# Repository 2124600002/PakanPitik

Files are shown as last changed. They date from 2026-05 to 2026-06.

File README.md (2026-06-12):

<div align="center">
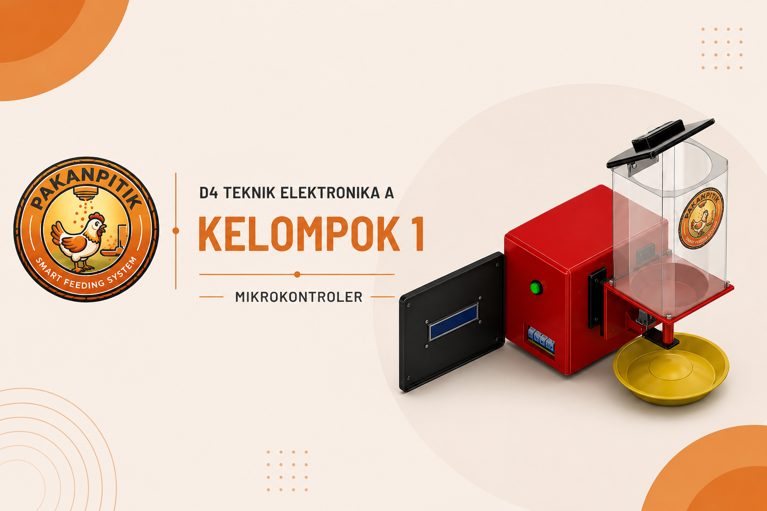
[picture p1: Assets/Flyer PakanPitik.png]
  
  <h1>PakanPitik</h1>
  <p><em>"Inovasi cerdas untuk meringankan beban peternak ayam lokal dan mewujudkan kemandirian pangan"</em></p>
  
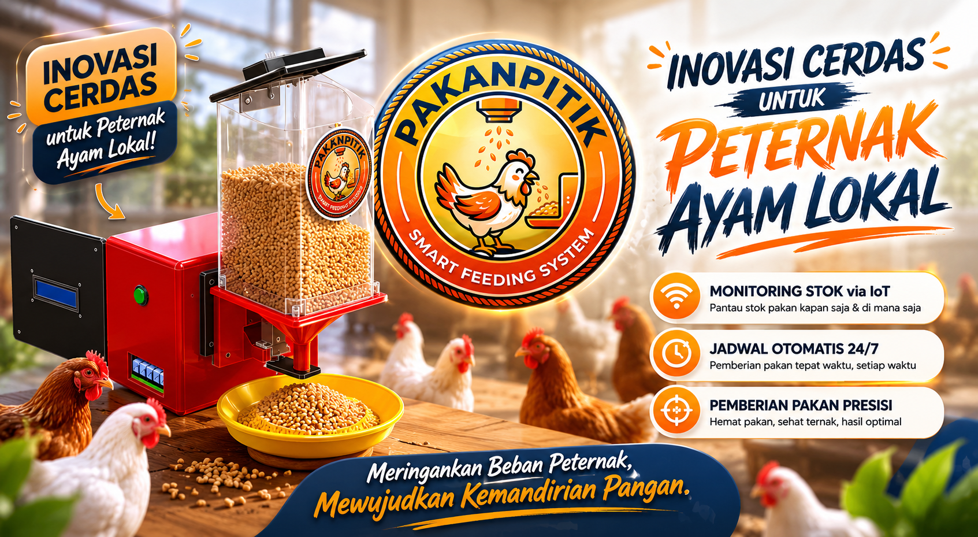
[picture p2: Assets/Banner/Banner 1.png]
  
  <br>

  <a href="https://drive.google.com/file/d/1gD_iWaVMiUkIKPEJ6pST8Kqmy6I9aC7F/view?usp=sharing" target="_blank">
    
  </a>

  <h3>Tautan Cepat (Quick Links)</h3>
  <a href="https://drive.google.com/file/d/1gD_iWaVMiUkIKPEJ6pST8Kqmy6I9aC7F/view?usp=sharing" target="_blank">
    
  </a>&nbsp;
  <a href="https://drive.google.com/file/d/1nLfeXrYmbJYR3gHJrhcpqqbRVYnBJc8w/view?usp=sharing" target="_blank">
    
  </a>&nbsp;
  <a href="https://drive.google.com/file/d/1knvE6YDGjDPh6mzlQrbH5e85_T9ZMVah/view?usp=sharing" target="_blank">
    
  </a>&nbsp;
  <a href="https://drive.google.com/file/d/19Tj84D4AJFjI7RVErF9s6wRXGpRxHWza/view?usp=sharing" target="_blank">
    
  </a>&nbsp;
  <a href="https://pakanpitik.netlify.app/" target="_blank">
    
  </a>&nbsp;
  <a href="https://www.figma.com/board/ega8brmlDySx4cgtJ8I34z/Mind-Map?node-id=0-1&t=bGIroIMrDm2866S6-1" target="_blank">
    
  </a>&nbsp;
  <a href="https://www.figma.com/board/ZbEIWirykj9XnRzqu0P9ER/Untitled?t=ggg7TkWvkMyIfHQo-1" target="_blank">
    
  </a>&nbsp;
  <a href="https://www.figma.com/design/T8wNbSInKxWhA6DcHFIXEK/Untitled?node-id=0-1&t=T81r4mzvqB2A10Lv-1" target="_blank">
    
  </a>&nbsp;
  <a href="https://wokwi.com/projects/465155487486760961" target="_blank">
    
  </a>&nbsp;
  <a href="https://canva.link/mmxi6qf92nia2kq" target="_blank">
    
  </a>
</div>

<hr>

# Deskripsi Proyek
<div align="justify">
Peternak ayam skala lokal seringkali dihadapkan pada tantangan rutinitas yang menguras waktu dan tenaga. Keterlambatan atau ketidakteraturan jadwal pakan dapat menyebabkan tingkat stres yang tinggi dan pertumbuhan unggas yang tidak merata. Di sisi lain, pemberian pakan secara manual seringkali tidak tertakar dengan baik, berujung pada pakan yang tercecer dan terbuang sia-sia (<em>food waste</em>). Hal ini tentu membebani biaya operasional peternak kecil yang sedang berjuang untuk mencapai kemandirian ekonomi.

Hadir sebagai solusi atas permasalahan tersebut, <strong>PakanPitik</strong> adalah sistem pemberi pakan ayam otomatis berbasis <em>Internet of Things</em> (IoT) yang dirancang aplikatif untuk meringankan beban peternak. PakanPitik mengeliminasi keharusan peternak untuk terus-menerus berada di kandang. Melalui integrasi <em>dashboard</em> cerdas, peternak dapat memantau sisa stok pakan secara <em>real-time</em> dari mana saja, dan sistem akan secara otomatis mendistribusikan pakan secara presisi sesuai jadwal. Dengan adanya fitur penyesuaian durasi pakan yang dinamis, takaran pakan dapat diatur agar selalu pas sesuai umur dan populasi ayam, sehingga menekan kerugian finansial akibat pakan yang terbuang.

Secara teknis, sistem ini menggunakan arsitektur <em>Single Source of Truth</em> (SSOT) di mana <strong>ATmega2560</strong> (diprogram dengan <em>Pure Bare-Metal C++</em>) bertindak sebagai <em>Master Brain</em> yang menangani seluruh logika aktuator dan kepastian waktu secara presisi tanpa <em>delay blocking</em>. Sementara itu, <strong>ESP32</strong> ditugaskan khusus sebagai jembatan jaringan (<em>WiFi Bridge</em>) untuk menghubungkan perangkat fisik di kandang dengan Cloud Web Dashboard.

Untuk mendukung sistem otomatisasi dan monitoring, digunakan beberapa komponen utama:
<ul>
  <li><strong>Ultrasonic Sensor HC-SR04</strong> → Mendeteksi jarak dan menghitung sisa ketersediaan (persentase) pakan dalam wadah penampung (hopper).</li>
  <li><strong>RTC DS3231</strong> → Modul <em>Real-Time Clock</em> untuk menjaga keakuratan jam pemicu jadwal pakan meskipun sistem sempat dimatikan atau putus koneksi internet.</li>
  <li><strong>Tombol Pakan Manual</strong> → Mengizinkan peternak untuk mengeksekusi pakan secara fisik langsung dari kandang (Active LOW) saat melakukan inspeksi.</li>
  <li><strong>Motor Servo MG90</strong> → Digerakkan oleh <em>Hardware Timer Fast PWM</em> untuk membuka dan menutup katup saluran pakan secara akurat.</li>
  <li><strong>LCD 16x2 (I2C)</strong> → Menampilkan informasi jam sistem, sisa stok pakan (%), dan status eksekusi secara lokal di kandang.</li>
  <li><strong>ATmega2560</strong> → Mikrokontroler AVR utama pusat kendali (<em>Master</em>).</li>
  <li><strong>ESP32</strong> → Penghubung internet via WiFi untuk sinkronisasi data ke <em>database</em> jarak jauh (<em>Slave/Bridge</em>).</li>
</ul>

Melalui sentuhan otomatisasi tepat guna ini, PakanPitik tidak hanya meningkatkan efisiensi waktu dan tenaga, tetapi juga memberdayakan peternak lokal agar dapat mengelola peternakannya dengan lebih modern, produktif, dan sejahtera.
</div>

# Tujuan Proyek
<div align="justify">
Merancang dan mengimplementasikan sistem pemberian pakan unggas otomatis berbasis IoT untuk memantau ketersediaan pakan secara <em>real-time</em> dan mengontrol aktuator distribusi pakan (berbasis jadwal atau <em>remote on-demand</em>). Proyek ini ditujukan untuk mempermudah pekerjaan peternak, mencegah pakan terbuang percuma melalui fitur durasi dinamis, dan menaikkan efisiensi operasional kandang.
</div>

### Support By :
>- **Dosen Pengampu** : Akhmad Hendriawan ST., MT.
>- **Mata kuliah** : Mikrokontroler
>- **Program Studi** : D4 Teknik Elektronika A
>- **Politeknik Elektronika Negeri Surabaya**

<hr>

# Anggota Kelompok 1

<div align="center">
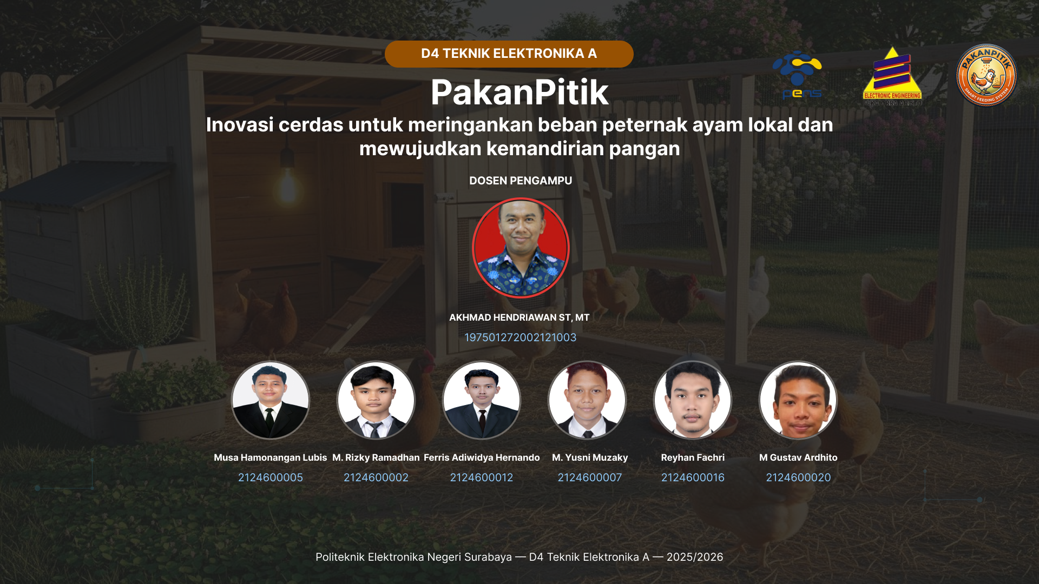
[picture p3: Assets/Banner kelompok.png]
  
</div>
<br>

| NRP | Nama | Jobdesk |
| :---: |:---:  | :---: |
| 2124600002 | M. Rizky Ramadhan  | Project Manager |
| 2124600005 | Musa Hamonangan L. | UI/UX Design |
| 2124600007 | Muh Yusni Muzaky F.| Hardware |
| 2124600012 | Ferris Adiwidya H. | Software & Documentation|
| 2124600016 | Reyhan Fachri A.H. | Software & Documentation|
| 2124600020 | M Gustav Ardhito | Hardware |

# Komponen Hardware

<div align="justify">
<ol>
  <li>Mikrokontroler ATmega2560 (Master Controller)</li>
  <li>Modul ESP32 WiFi (Bridge Controller)</li>
  <li>Modul Real-Time Clock (RTC) DS3231</li>
  <li>Sensor Jarak Ultrasonik HC-SR04</li>
  <li>Motor Servo DC MG90/MG996R</li>
  <li>Modul Display LCD 16x2 + I2C Backpack (PCF8574)</li>
  <li>Push Button (Tactile Switch)</li>
  <li>Modul Step-Down DC-DC LM2596 (12V ke 5V)</li>
  <li>Logic Level Converter Bi-Directional (Jembatan UART 5V ↔ 3.3V)</li>
  <li>Power Supply 12V DC</li>
</ol>
</div>

<hr>

# Visualisasi Sistem

### Desain Hardware 
<div align="center">
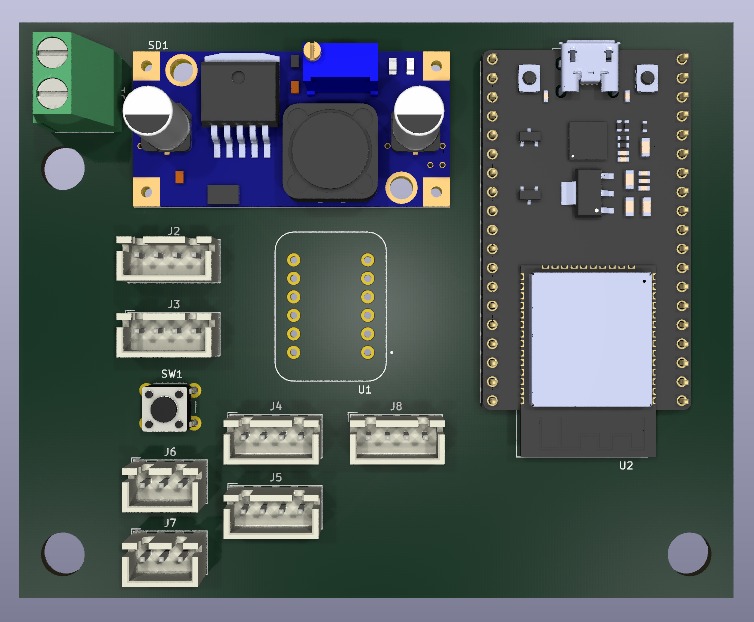
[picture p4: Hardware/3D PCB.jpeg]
  
  <p align="justify">
    Tampilan 3D dari board PCB slave untuk sistem PakanPitik.
  </p>
  
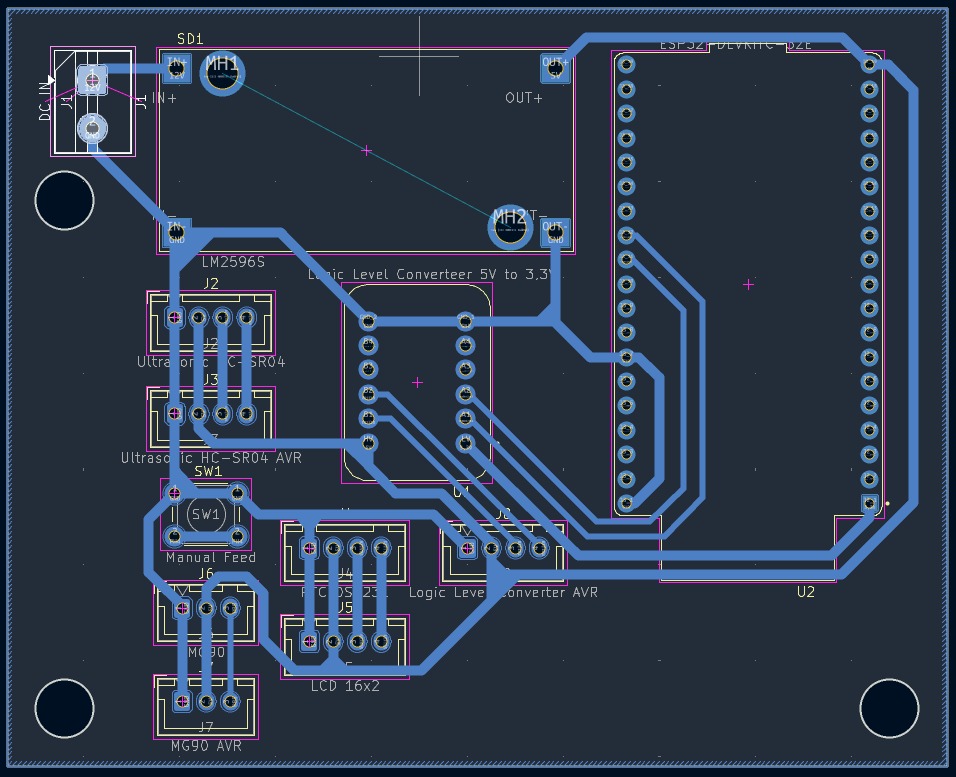
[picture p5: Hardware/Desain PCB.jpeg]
  
  <p align="justify">
    Wiring pada board PCB slave dengan menggunakan bottom layer saja untuk menghemat biaya dan mempermudah dalam proses pencetakan.
  </p>

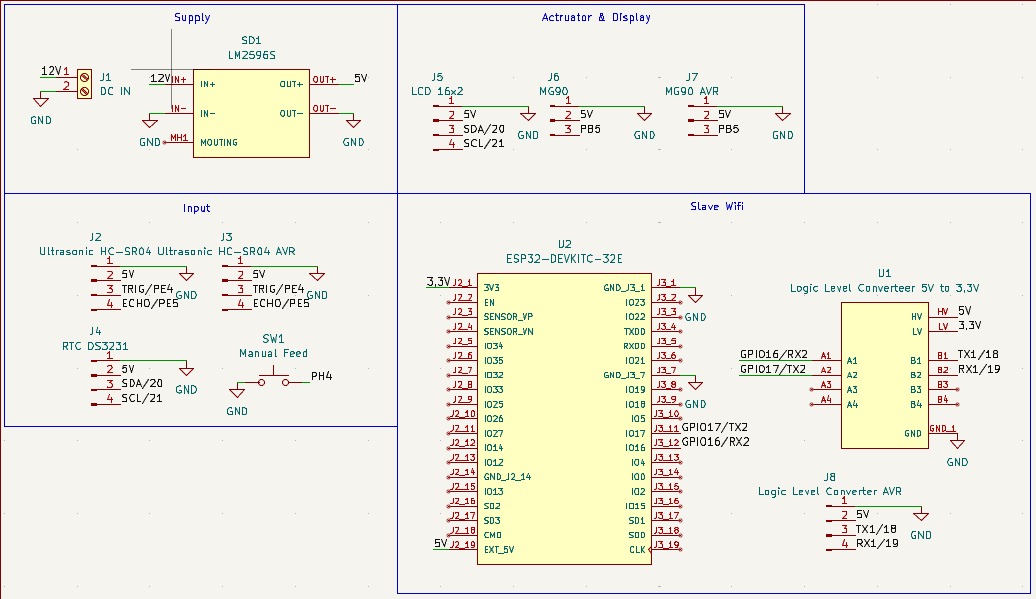
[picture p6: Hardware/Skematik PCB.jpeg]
  
  <p align="justify">
    Desain skematik dari board PCB slave yang digunakan pada PakanPitik, dimana dari board PCB slave ini nantinya akan banyak dihubungkan menggunakan konektor JST melalui kabel menuju board shield ATmega2560.
  </p>
</div>
<br>

### Desain 3D
<div align="center">
<br>
  <a href="https://drive.google.com/file/d/19Tj84D4AJFjI7RVErF9s6wRXGpRxHWza/view?usp=sharing" target="_blank">
    
  </a>
  <br><br>
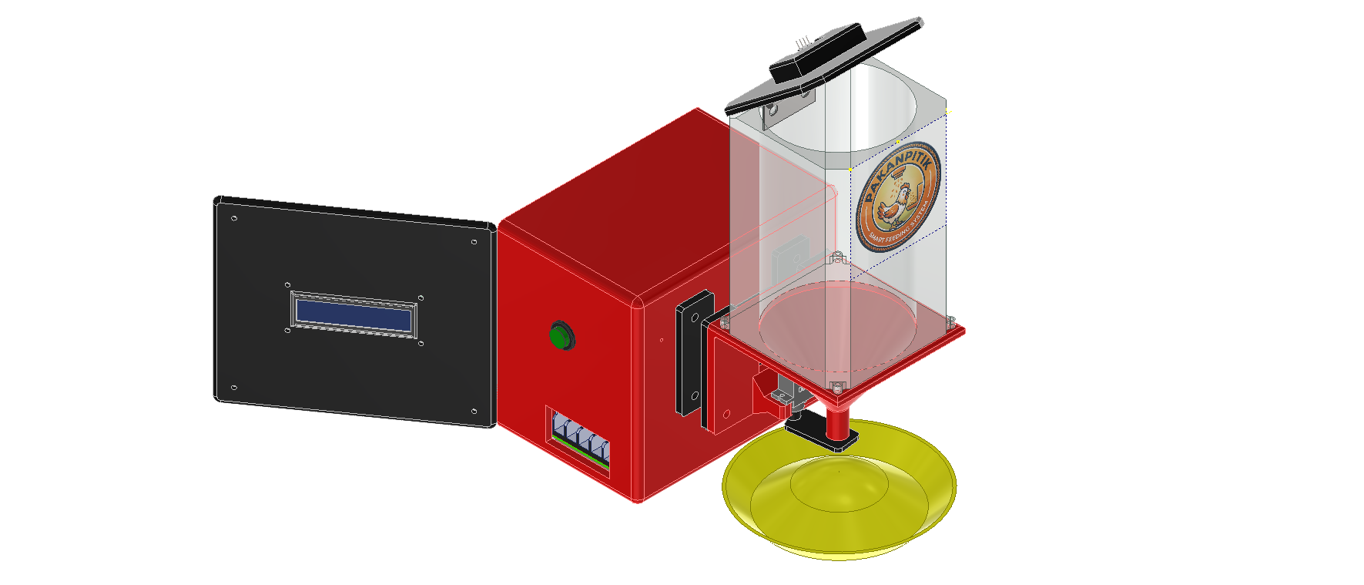
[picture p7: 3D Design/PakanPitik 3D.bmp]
  
  <p align="justify">
    Tampak desain 3D dari PakanPitik yang dirancang menggunakan perangkat lunak Inventor. Pada desain tersebut, dapat dilihat penampung makanan unggas, servo sebagai aktuator untuk membuka dan menutup saluran pakan melalui corong, serta bracket penghubung antara alat pemberi pakan dan box IoT. Bracket ini dapat digunakan untuk menggantungkan alat pada triplek atau papan dengan ketebalan 2cm. Terdapat juga box IoT yang pada bagian depannya dilengkapi LCD 16x2 I2C, tombol pakan manual berwarna hijau, serta port input untuk power supply 12V 5A di bagian bawah. Selain itu, piring atau wadah pakan ditempatkan di bagian bawah penampung sebagai area keluarnya pakan.
  </p>

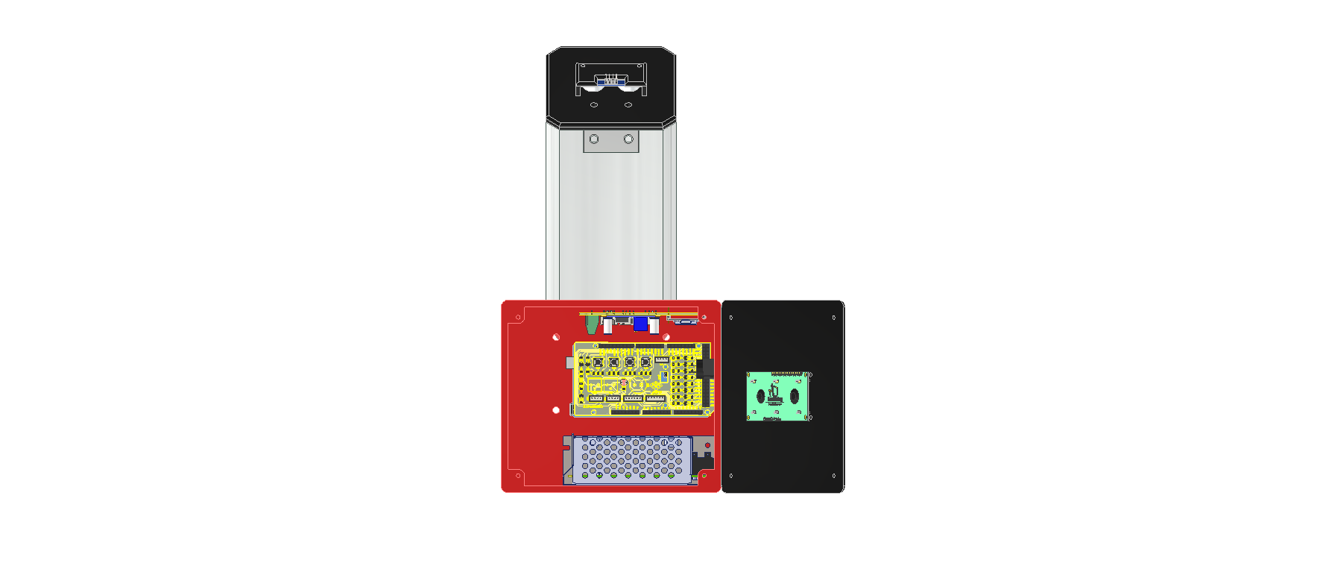
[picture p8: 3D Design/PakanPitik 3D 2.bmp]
  
  <p align="justify">
    Tampak bagian dalam Box IoT yang memuat shield dan board ATmega2560 sebagai master, board slave untuk komunikasi sensor dan aktuator, serta ESP32 sebagai modul WiFi (modul WiFi ini dapat diganti dengan alternatif yang lebih terjangkau, namun ESP32 dipilih karena ketersediaan perangkat). LCD 16x2 terpasang pada penutup box, sedangkan Power Supply 12V 5A berfungsi sebagai sumber daya utama. Penggunaan Power Supply langsung dipilih alih-alih adaptor biasa agar sistem mampu beroperasi secara stabil dan tangguh selama 24 jam nonstop.
  </p>

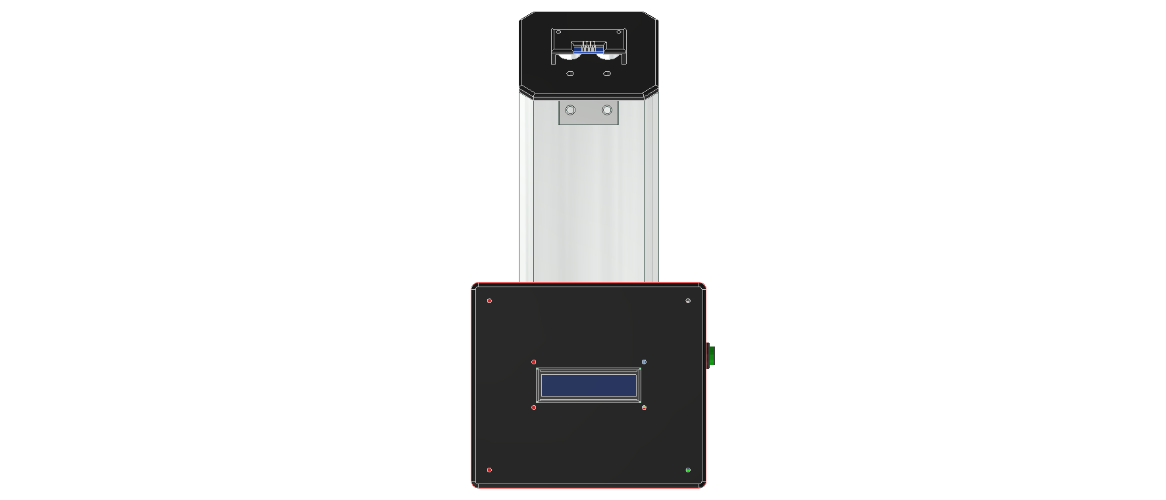
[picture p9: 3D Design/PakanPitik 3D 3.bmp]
  
  <p align="justify">
    Tampak depan dari alat PakanPitik saat box tertutup, dengan LCD 16x2 yang berfungsi sebagai layar informasi sistem.
  </p>

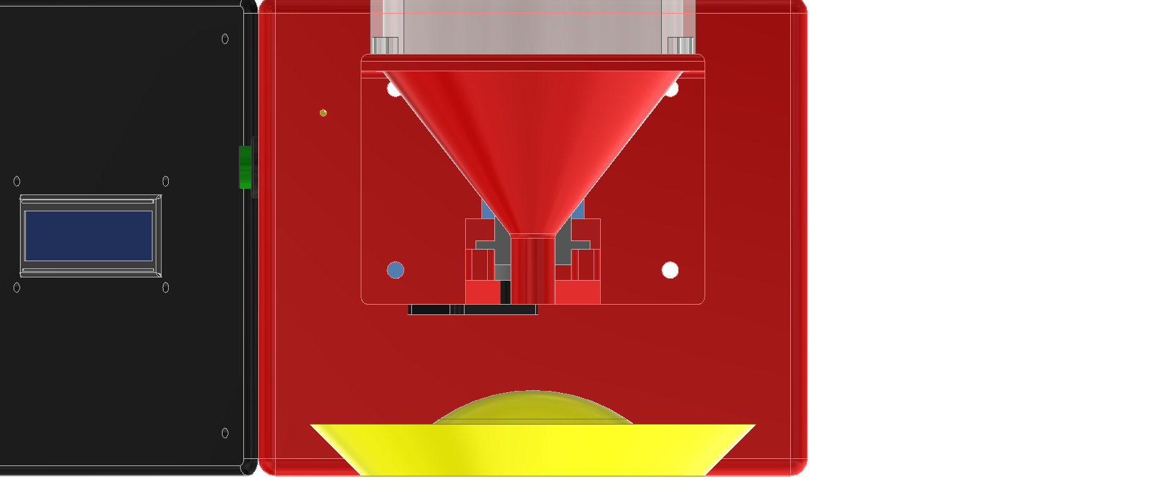
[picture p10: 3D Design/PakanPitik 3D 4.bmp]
  
  <p align="justify">
    Tampak bagian corong di dasar penampung pakan, dilengkapi dengan penutup yang digerakkan oleh servo MG90 untuk memastikan daya tahan yang cukup kuat.
  </p>

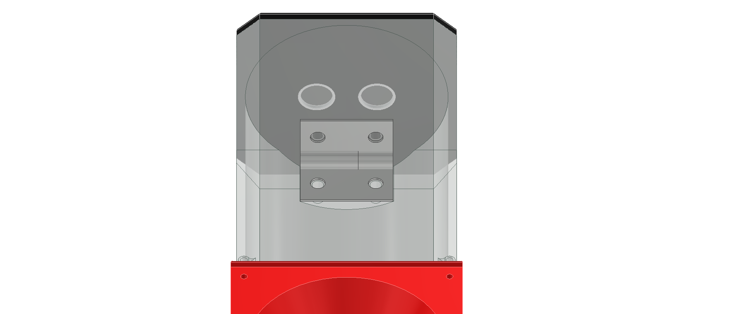
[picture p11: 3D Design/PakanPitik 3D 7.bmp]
  
  <p align="justify">
    Penempatan sensor ultrasonik pada penutup paling atas penampung pakan, menghadap ke bawah. Fungsinya adalah untuk mengukur level atau sisa pakan di dalam wadah secara real-time.
  </p>

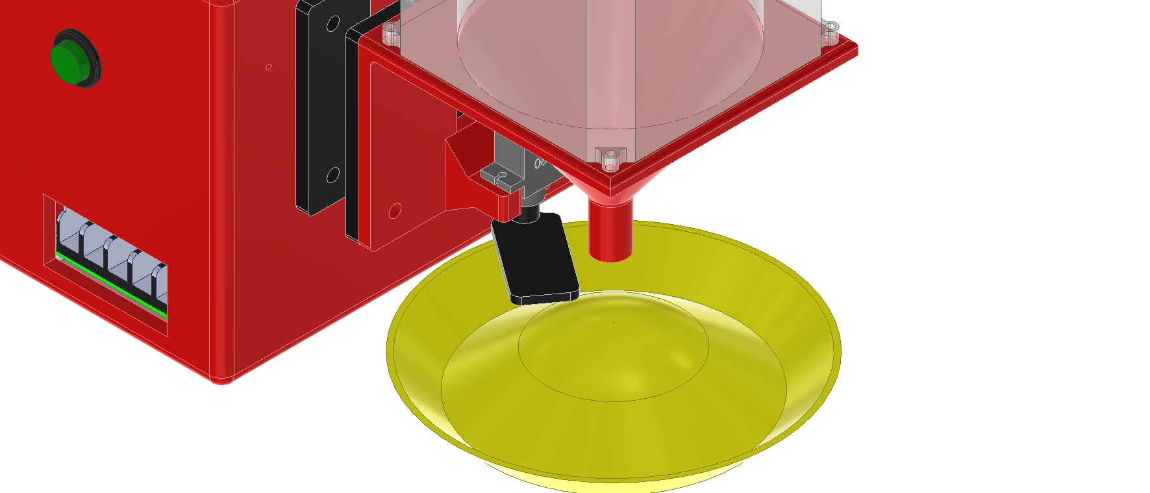
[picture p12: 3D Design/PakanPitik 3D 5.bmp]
  
  <p align="justify">
    Posisi servo saat terbuka. Ketika jadwal pakan otomatis tiba atau tombol pakan manual ditekan, servo akan membuka katup. Durasi bukaan ini dapat diatur langsung melalui antarmuka GUI (Web Dashboard).
  </p>

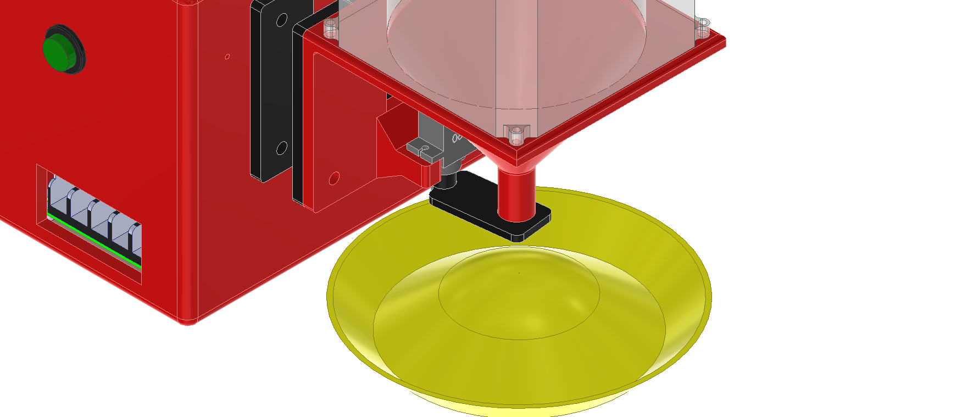
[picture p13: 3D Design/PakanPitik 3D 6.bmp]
  
  <p align="justify">
    Posisi servo saat tertutup. Saat sistem sedang tidak aktif atau belum mencapai waktu pemberian pakan otomatis, servo akan menutup rapat bagian bawah corong penampung untuk mencegah pakan keluar secara tidak sengaja dan menghindari masuknya semut atau hama lain ke dalam wadah.
  </p>
</div>
<br>

### Blok Diagram
<div align="center">
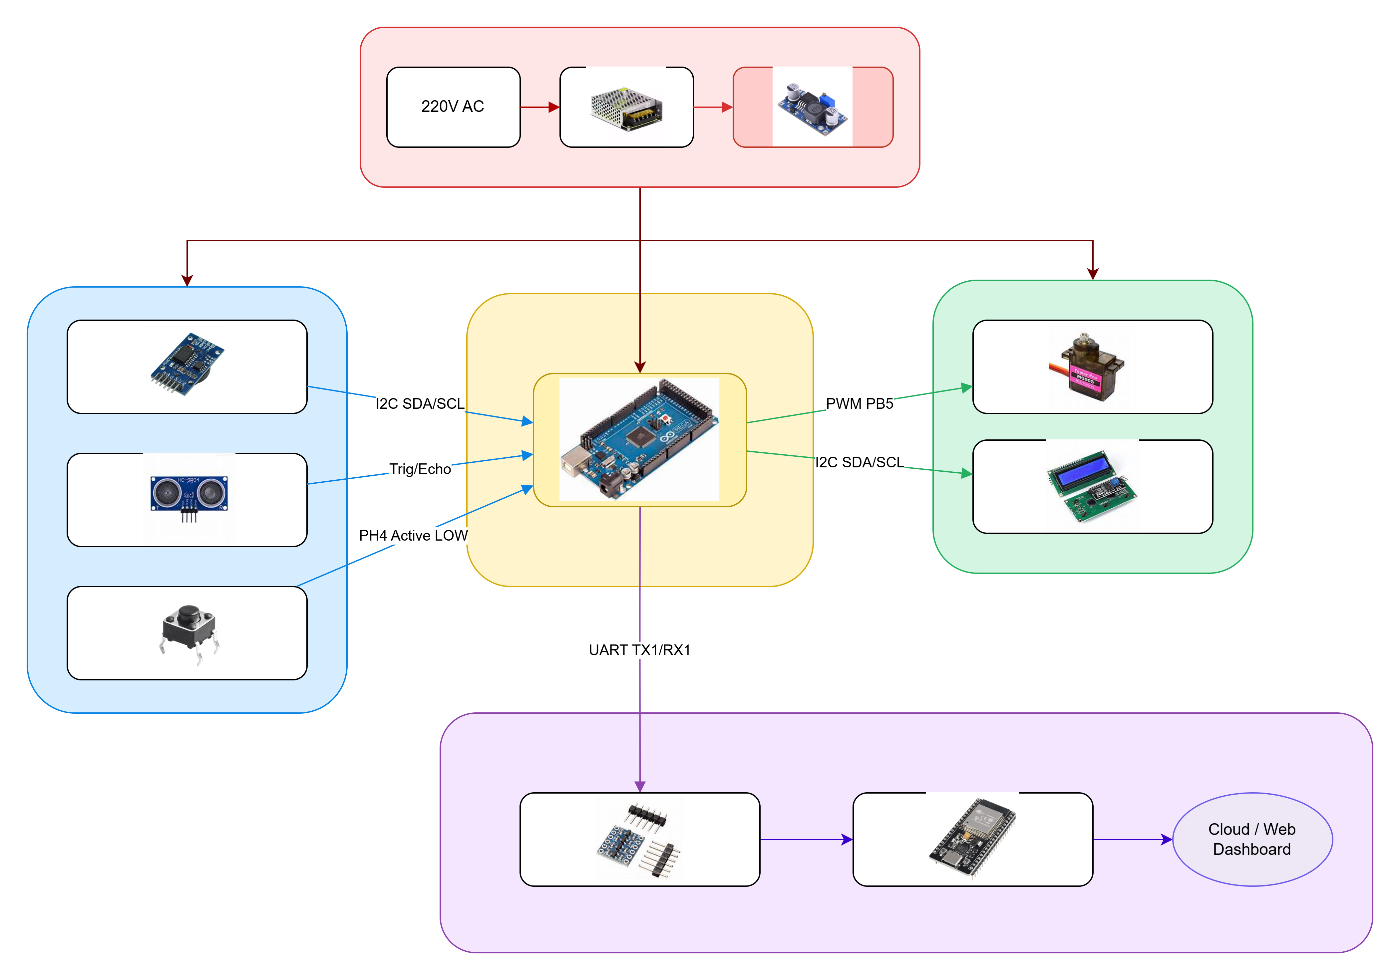
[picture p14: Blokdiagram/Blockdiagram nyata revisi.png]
  
  <p align="justify">
    Blok diagram di atas merepresentasikan alur koneksi dan komunikasi dari perangkat keras PakanPitik yang sebenarnya (sistem nyata terimplementasi), bukan adaptasi sementara berbasis Shield ATmega2560.
  </p>
</div>
<br>

### Flowchart
<div align="center">
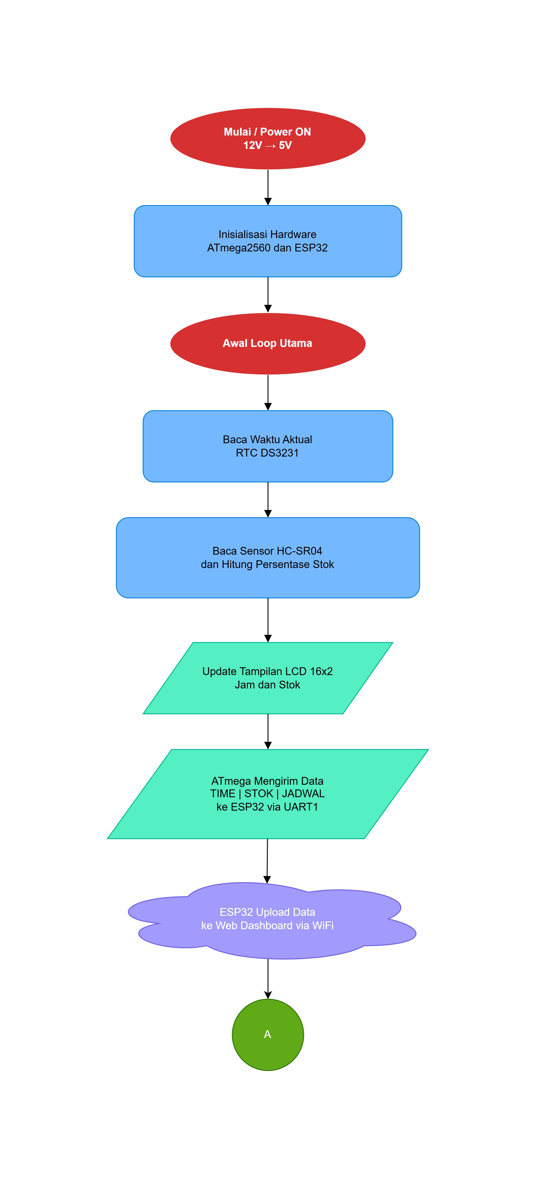
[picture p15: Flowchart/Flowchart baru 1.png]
  
  <p align="justify">
    Flowchart logika yang menggambarkan alur kerja sistem PakanPitik (Bagian Pertama).
  </p>

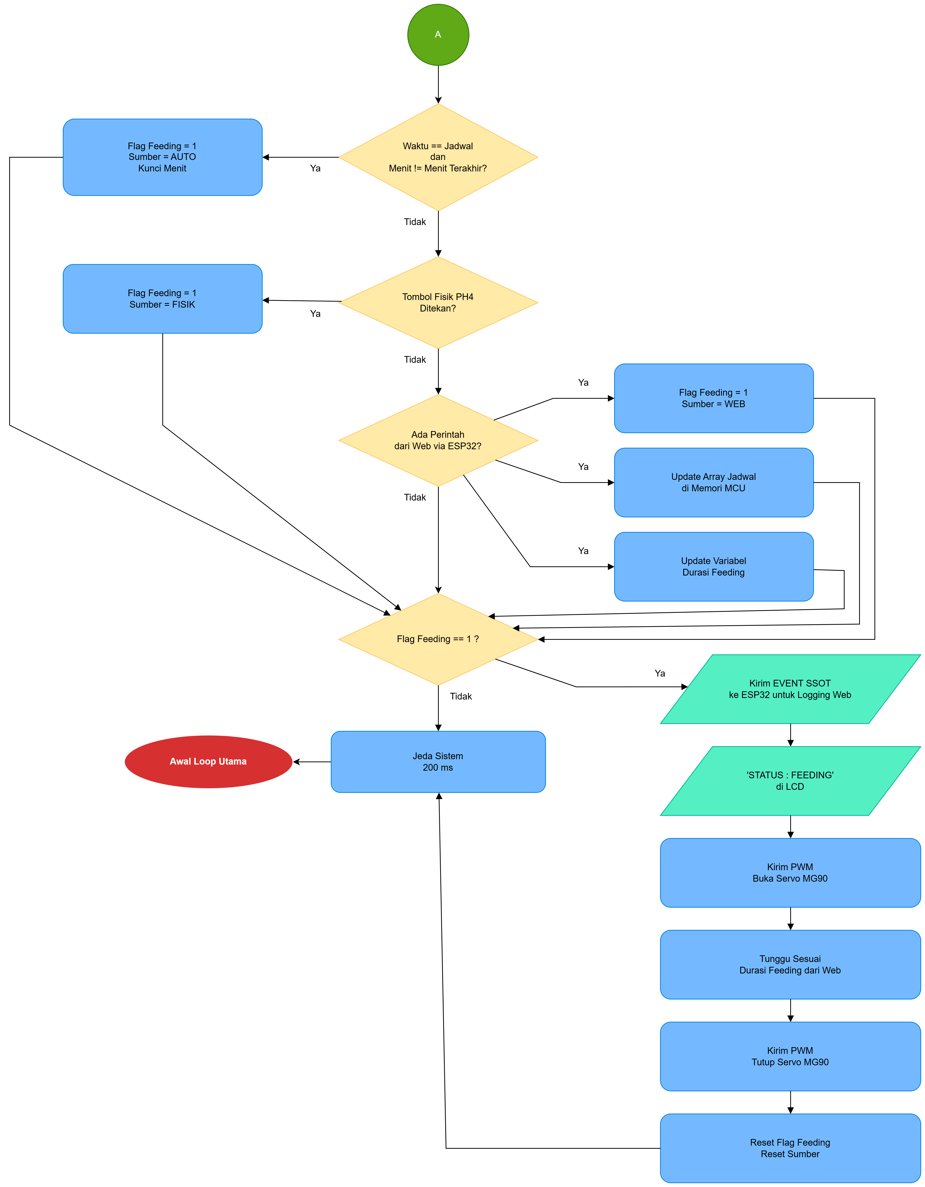
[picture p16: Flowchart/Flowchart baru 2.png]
  
  <p align="justify">
    Flowchart logika yang menggambarkan alur kerja sistem PakanPitik (Bagian Kedua).
  </p>
</div>
<br>

### Mindmap Diagram
<div align="center">
  <br>
  <a href="https://www.figma.com/board/ega8brmlDySx4cgtJ8I34z/Mind-Map?node-id=0-1&t=bGIroIMrDm2866S6-1" target="_blank">
    
  </a>
  <br><br>
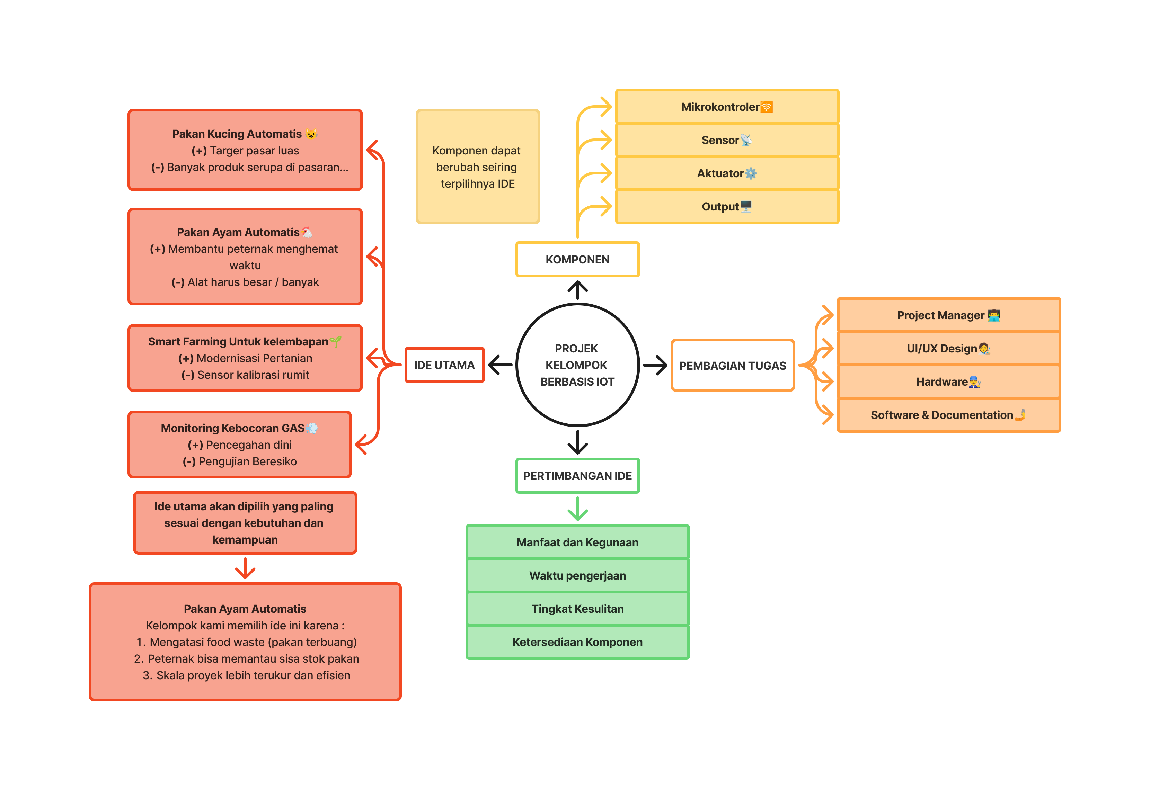
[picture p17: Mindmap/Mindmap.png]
  
  <p align="justify">
    Mindmap ini menggambarkan tahapan brainstorming dan perencanaan strategis awal untuk proyek kelompok berbasis IoT. Diagram ini memetakan beberapa alternatif ide penyelesaian masalah, kriteria utama dalam menyeleksi ide (seperti manfaat, waktu, kesulitan, dan ketersediaan komponen), hingga gambaran umum kebutuhan perangkat keras. Melalui pemetaan ini, kelompok secara spesifik memutuskan untuk mengembangkan Pakan Ayam Otomatis (PakanPitik) karena dinilai paling efektif dalam mengatasi food waste, memungkinkan pemantauan sisa stok pakan, dan memiliki skala proyek yang terukur. Selain itu, diagram ini juga memperlihatkan struktur pembagian tugas masing-masing anggota tim.
  </p>
</div>
<br>

### Fishbone Diagram
<div align="center">
  <br>
  <a href="https://www.figma.com/board/ZbEIWirykj9XnRzqu0P9ER/Untitled?t=ggg7TkWvkMyIfHQo-1" target="_blank">
    
  </a>
  <br><br>
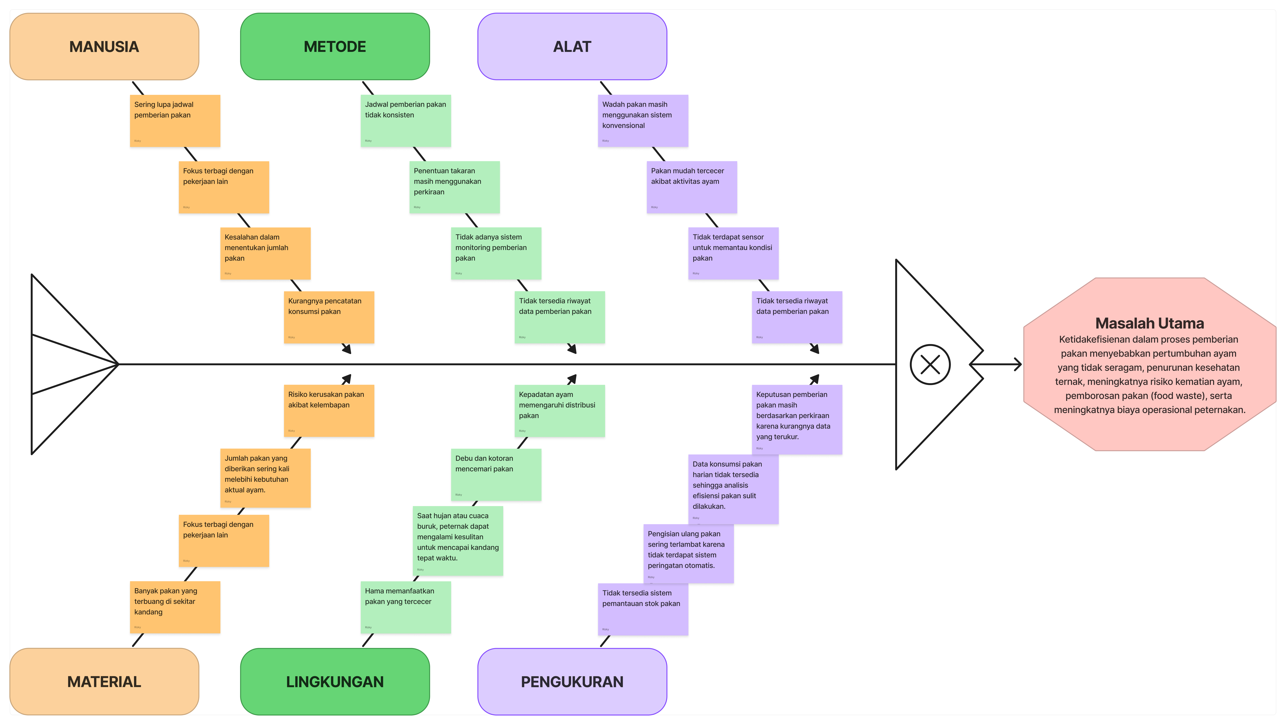
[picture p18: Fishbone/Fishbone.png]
  
  <p align="justify">
   Diagram Fishbone digunakan untuk membedah akar permasalahan dari ketidakefisienan proses pemberian pakan unggas secara manual. Diagram ini mengkategorikan penyebab masalah ke dalam enam aspek utama, yaitu manusia, metode, alat, material, lingkungan, dan pengukuran (seperti sering lupa jadwal, wadah konvensional yang membuat pakan tercecer, hingga tidak adanya riwayat data konsumsi). Secara keseluruhan, akumulasi dari keenam faktor tersebut bermuara pada satu masalah utama yang merugikan peternak, yaitu pemborosan pakan (food waste), ketidakseragaman pertumbuhan ayam, serta melambungnya biaya operasional.
  </p>
</div>
<br>

### UI/UX Web Dashboard
<div align="center">
  <br>
  <a href="https://www.figma.com/design/T8wNbSInKxWhA6DcHFIXEK/Untitled?node-id=0-1&t=T81r4mzvqB2A10Lv-1" target="_blank">
    
  </a>&nbsp;
  <a href="https://pakanpitik.netlify.app/" target="_blank">
    
  </a>
  <br><br>
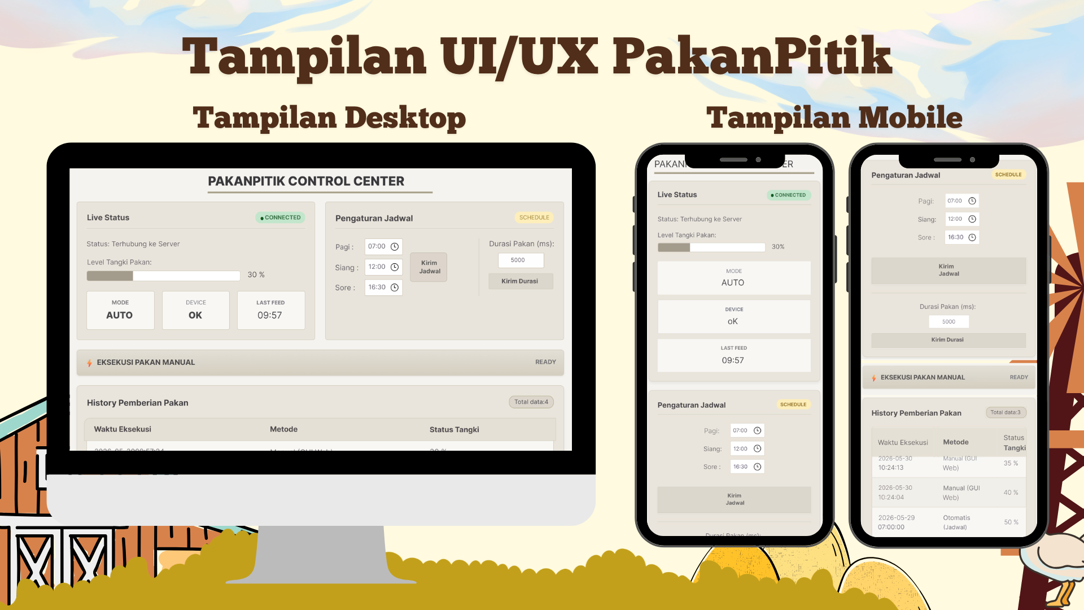
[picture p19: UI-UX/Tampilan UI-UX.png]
  
  <p align="justify">
    Tampilan UI/UX Web Dashboard yang dirancang menggunakan Figma untuk memantau alat PakanPitik via WiFi di berbagai perangkat. Panel "Live Status" menampilkan persentase sisa pakan di penampung (berdasarkan pembacaan sensor Ultrasonik HC-SR04) dan waktu pemberian pakan terakhir. Di sebelah kanan, terdapat form untuk mengatur jadwal pakan otomatis (Pagi, Siang, Sore) beserta input durasi bukaan servo (dalam milidetik). Di bagian tengah, tersedia tombol interaktif untuk mengeksekusi pemberian pakan secara manual. Bagian paling bawah menampilkan tabel log history yang mencatat detail setiap aktivitas operasional alat secara real-time.
  </p>
</div>
<br>

### Simulasi Program Wokwi
<div align="center">
  <br>
  <a href="https://wokwi.com/projects/465155487486760961" target="_blank">
    
  </a>
  <br><br>
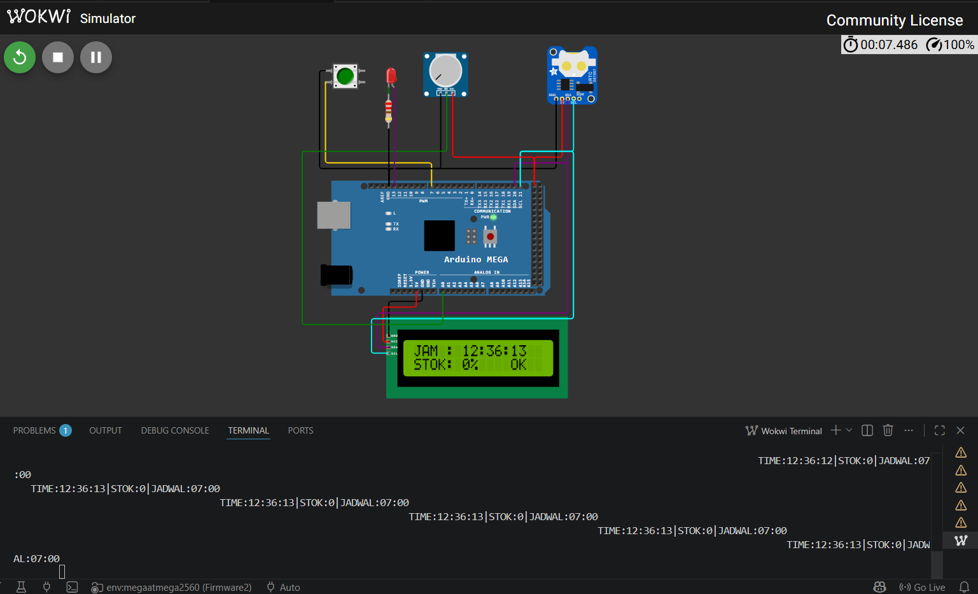
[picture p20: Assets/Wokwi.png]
  
  <p align="justify">
    Tangkapan layar di atas menunjukkan pengujian simulasi logika sistem PakanPitik yang sementara ini disesuaikan dengan komponen input/output yang tersedia pada Shield PCB ATmega2560.
  </p>
</div>

<hr>

# Cara Kerja Sistem
<div align="justify">
<ol>
  <li><strong>Inisialisasi & Pembacaan Data:</strong> Saat dihidupkan, ATmega2560 menarik data waktu <em>real-time</em> (Jam, Menit, Detik) dari RTC DS3231 via I2C, serta mengukur pantulan frekuensi dari HC-SR04 untuk dikalkulasi menjadi persentase stok pakan (0-100%).</li>
  <li><strong>Sinkronisasi Tampilan & Cloud:</strong> Data waktu dan stok ditampilkan ke layar LCD 16x2. Secara bersamaan, ATmega2560 merangkai string data dan mengirimkannya melalui komunikasi Serial (UART1) ke ESP32. ESP32 kemudian menembakkan data tersebut ke Web Dashboard via koneksi WiFi.</li>
  <li><strong>Logika Pemicu (Triggers):</strong> Sistem terus bersiaga memeriksa 3 kondisi pemicu:
    <ul>
      <li><em>Otomatis:</em> Apakah waktu saat ini sama persis dengan jadwal memori? (Dilengkapi <em>debouncing</em> agar tidak terjadi <em>log</em> ganda di detik yang sama).</li>
      <li><em>Fisik:</em> Apakah tombol manual pada kandang ditekan?</li>
      <li><em>Remote:</em> Apakah ada perintah eksekusi pakan masuk dari Web Dashboard melalui ESP32?</li>
    </ul>
  </li>
  <li><strong>Eksekusi Aktuator Dinamis:</strong> Jika salah satu pemicu aktif, ATmega2560 akan memancarkan sinyal <em>Fast PWM</em> (Hardware Timer) untuk membuka katup motor Servo MG90. Lama katup terbuka bergantung pada variabel <strong>Durasi Pakan Dinamis</strong> yang bisa diatur peternak langsung dari Web Dashboard (untuk mencegah pakan terbuang).</li>
  <li><strong>Perekaman Log (History):</strong> Sebelum pakan turun, ATmega2560 secara mutlak mengirimkan paket data <em>Event</em> (<code>EVENT:AUTO</code>, <code>EVENT:PHYSICAL</code>, atau <code>EVENT:GUI</code>) ke Web Dashboard agar waktu dan alasan pakan keluar tercatat rapi di tabel <em>History</em>.</li>
</ol>
</div>

# Panduan Penggunaan
<div align="justify">
<ol>
  <li><strong>Persiapan Daya:</strong> Hubungkan alat ke sumber listrik PLN pada Power Supply 12V nya. Sistem manajemen daya internal (LM2596) akan menstabilkan tegangan operasi komponen ke 5V.</li>
  <li><strong>Koneksi Jaringan:</strong> Pastikan alat menyala dalam jangkauan sinyal WiFi kandang agar ESP32 dapat secara otomatis merutekan sistem ATmega2560 ke <em>database</em> Cloud.</li>
  <li><strong>Akses Dashboard:</strong> Buka <em>browser</em> di <em>smartphone</em> atau PC, lalu akses halaman Web Dashboard PakanPitik milik Anda.</li>
  <li><strong>Pemantauan:</strong> Pada layar Web (atau LCD lokal), Anda dapat melihat jam operasional alat saat ini dan persentase (%) ketersediaan pakan di dalam tangki hopper.</li>
  <li><strong>Pengaturan Jadwal & Durasi:</strong> Pada panel kendali Web, atur 3 jadwal makan utama (Pagi, Siang, Sore) berformat HH:MM. Masukkan juga <strong>Durasi Pakan</strong> dalam milidetik (contoh: isi 3000 untuk buka katup selama 3 detik) untuk menyesuaikan takaran makanan unggas. Tekan "Kirim" atau "Set".</li>
  <li><strong>Eksekusi Darurat:</strong> Jika ingin memberi pakan instan di luar jadwal, tekan tombol fisik pada alat, atau klik tombol <strong>"Beri Makan Manual"</strong> langsung dari Web Dashboard Anda. Log eksekusi akan langsung tercatat pada tabel riwayat <em>website</em>.</li>
</ol>
</div>

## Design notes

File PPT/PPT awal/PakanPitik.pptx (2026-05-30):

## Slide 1


UI UX Design

Project Manager

Software & Documentation

Hardware

Software & Documentation

Hardware

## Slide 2

Mind Mapping FigJam

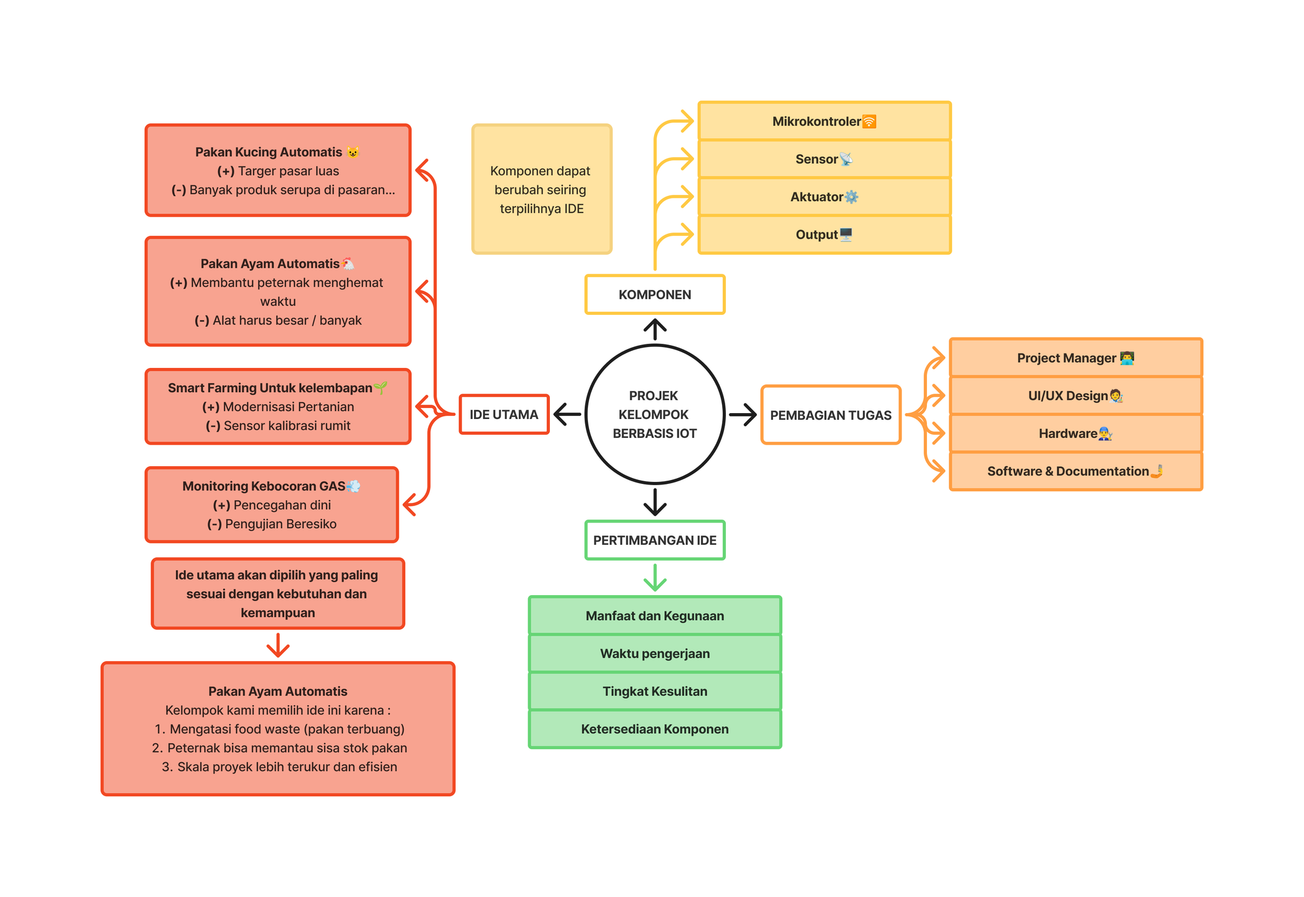
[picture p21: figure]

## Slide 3

Diskripsi Masalah Nyata

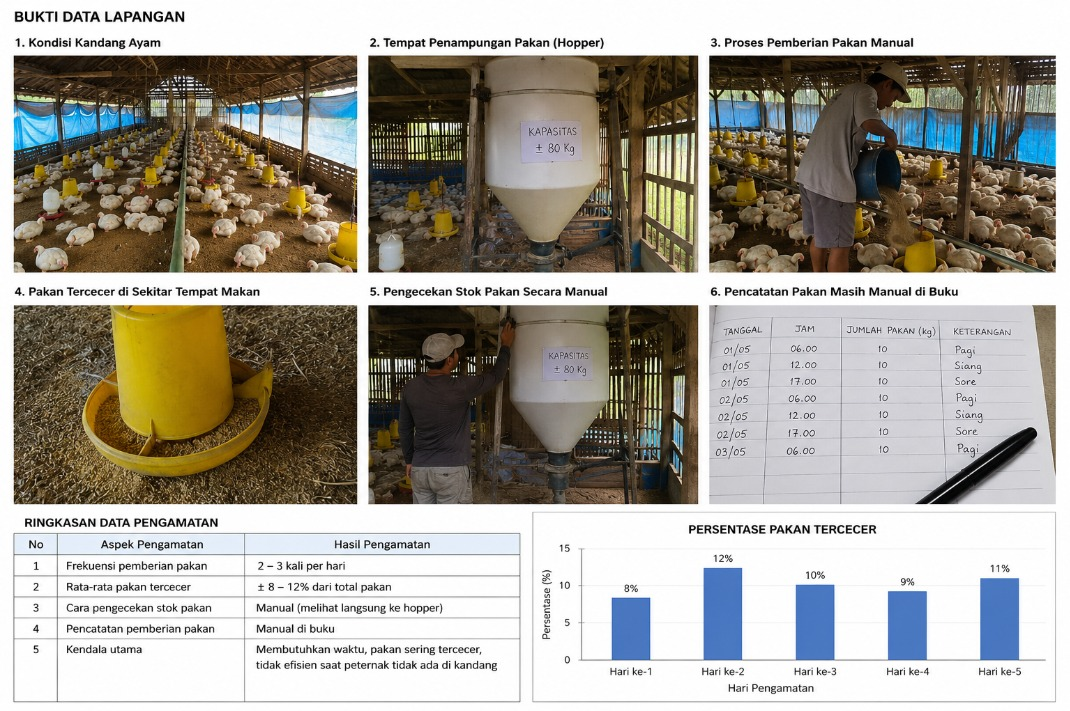
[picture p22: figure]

Project PakanPitik ini kami kembangkan untuk tujuan memenuhi kebutuhan peternak untuk sistem pemberian pakan otomatis yang efisien, dan mampu memantau stok secara real-time, mengurangi pemborosan pakan, dan mempermudah pengelolaan dikandang.

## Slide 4

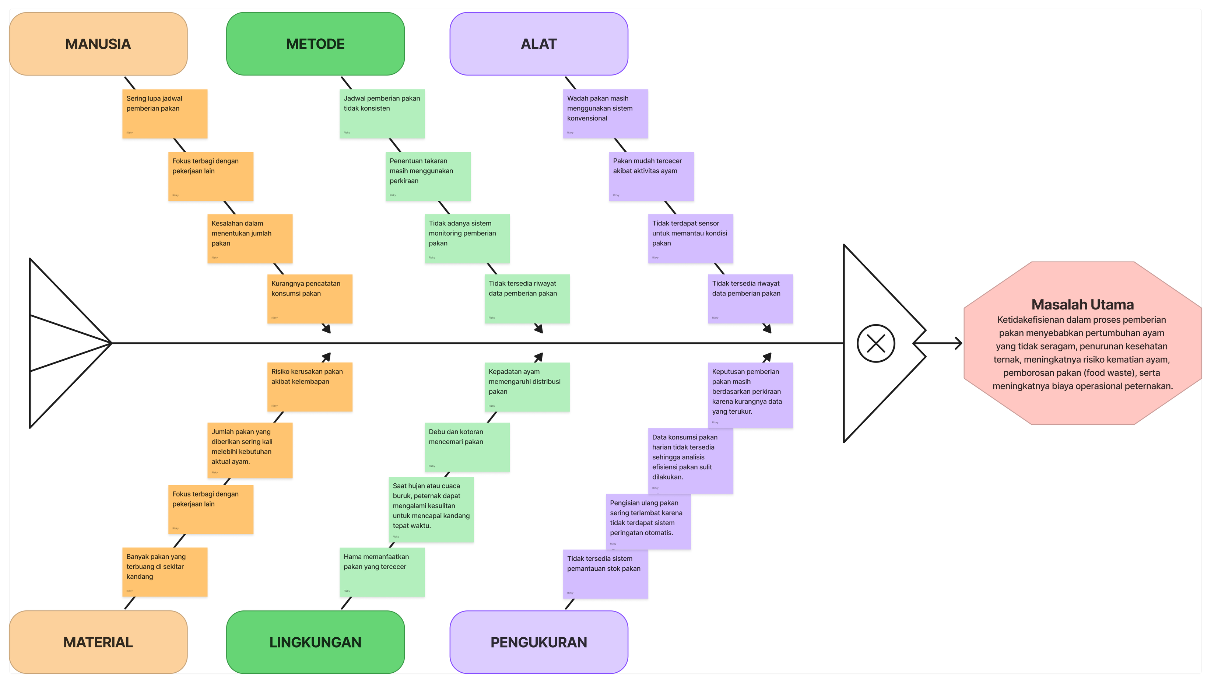
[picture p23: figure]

FishBone Diagram

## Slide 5

SDGs Impact - PakanPitik

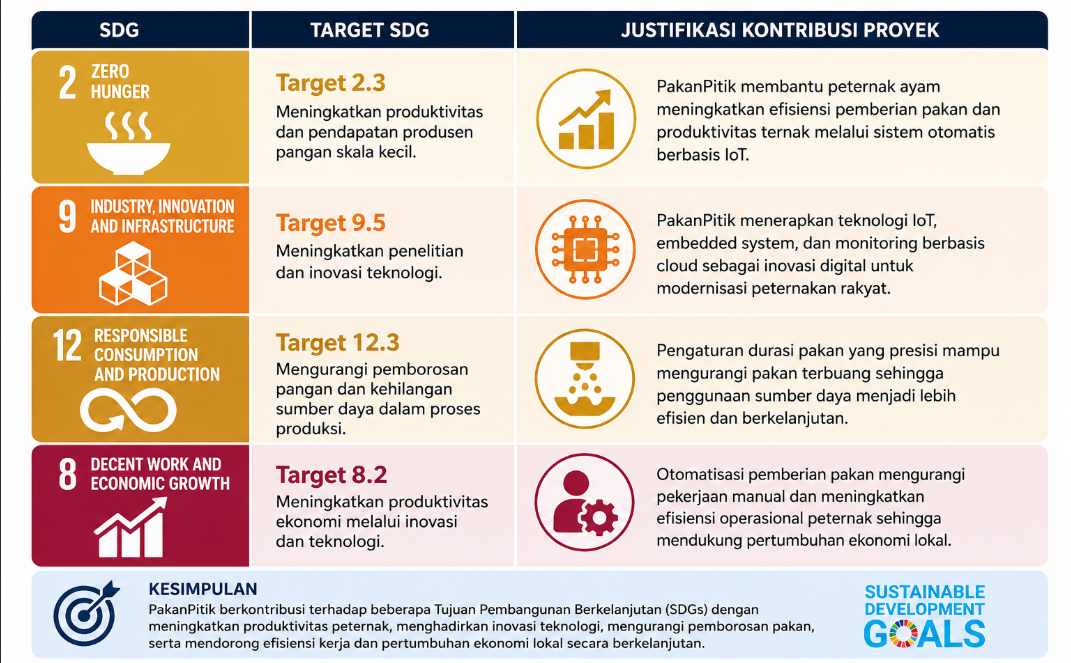
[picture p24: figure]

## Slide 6

Diagram Blok Sistem

Berdasarkan blokdiagram disamping kami menggunakan ATmega2560 yang memiliki fungsi untuk pusat kendali yang akan menerima data dari RTC DS3231, sensor ultrasonic HC-SR04, dan untuk tombol manual. kemudian dari data itu sistem dapat mengontrol servo MG90 untuk menyalurkan pakan secara otomatis. yang dapat kita lihat melalui info yang ada di LED 16 X 2
untuk memantau data stok pakan dan pemberian pakan kita bisa memantau liwat Web dashboard berbasis IoT.

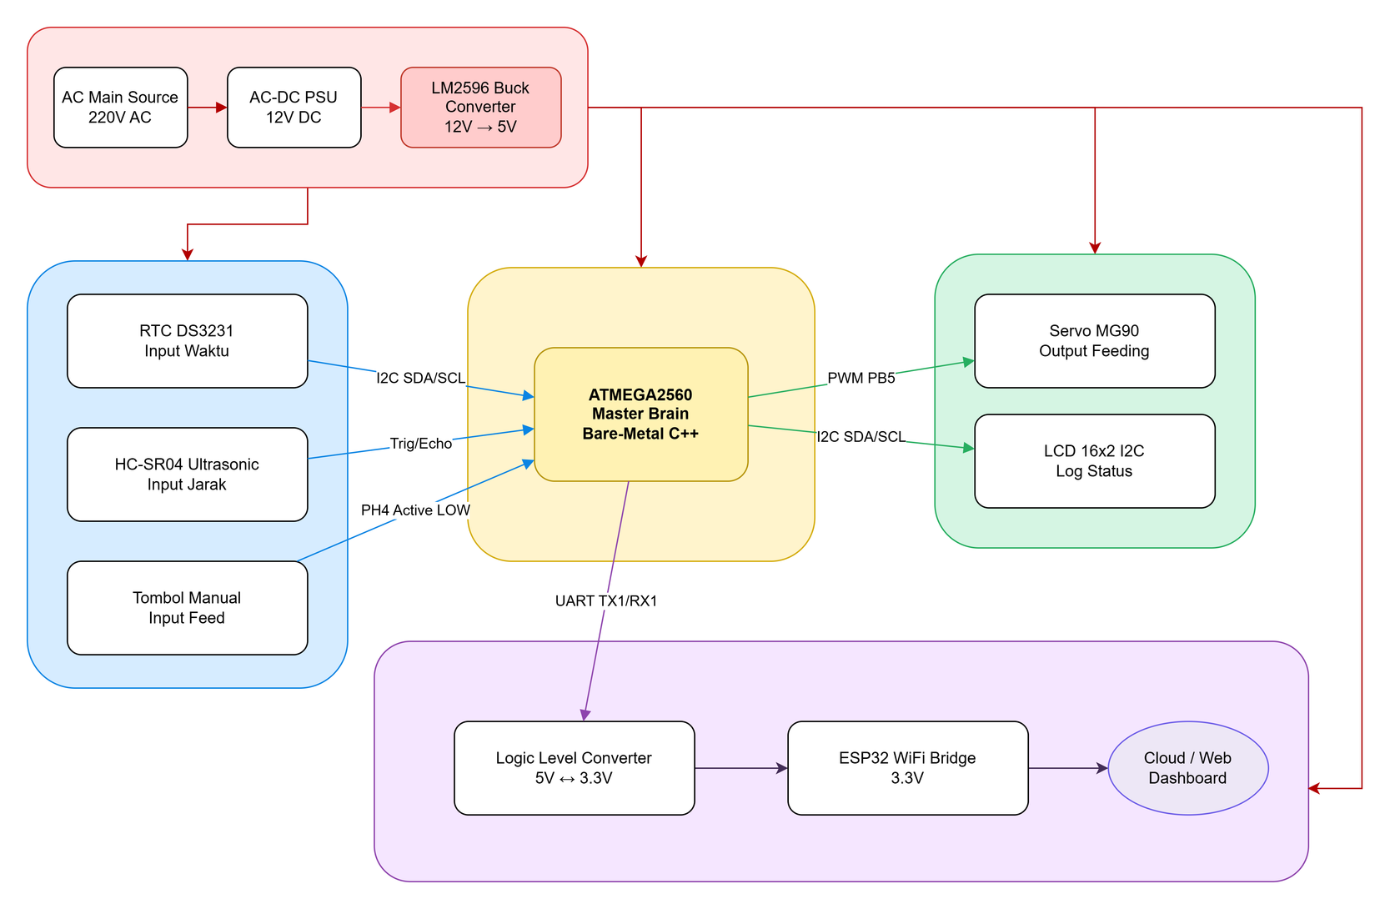
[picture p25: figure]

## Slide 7

UI/UX Desain

User → Dashboard → Atur Jadwal/Durasi → Kirim ke ESP32 → ATmega2560 Memproses → Servo Mengeluarkan Pakan → Data Tersimpan di Cloud → Riwayat & Status Ditampilkan Kembali ke User.

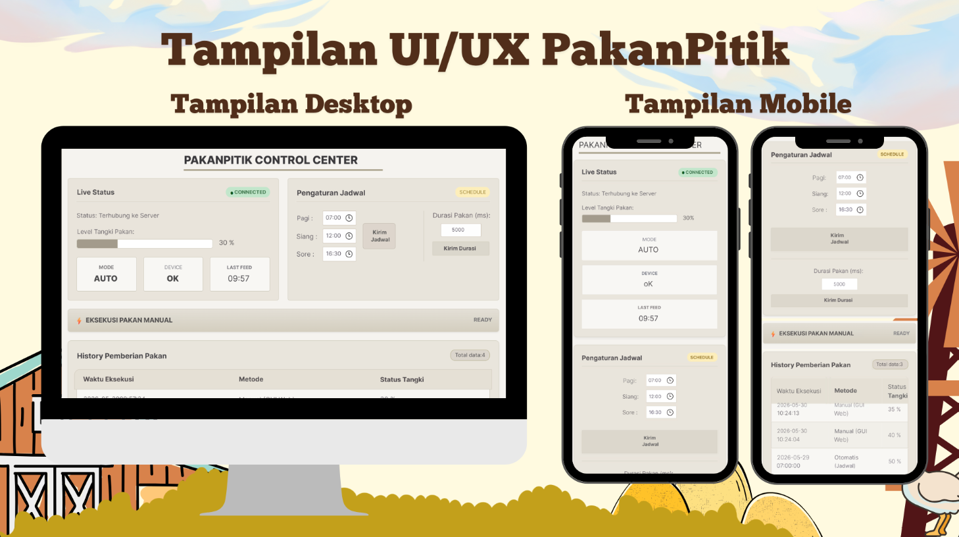
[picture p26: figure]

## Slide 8

Pin Mapping

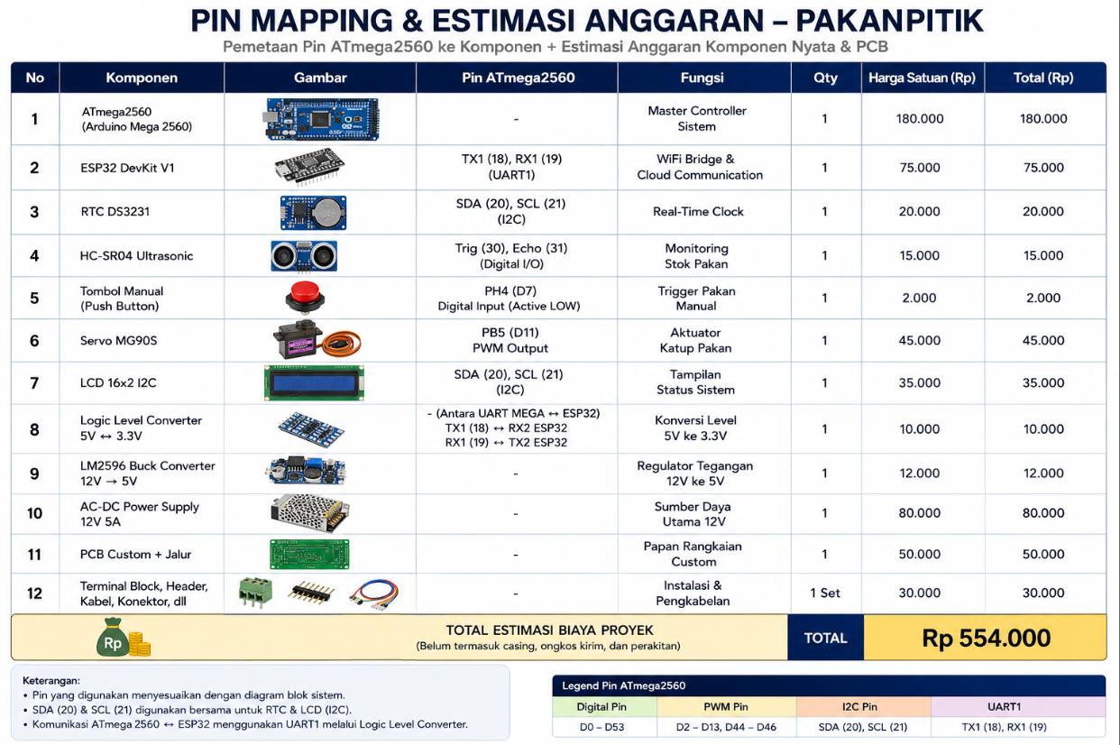
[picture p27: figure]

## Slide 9

Dokumentasi pengerjaan

Contribution Graph GitHub tim.

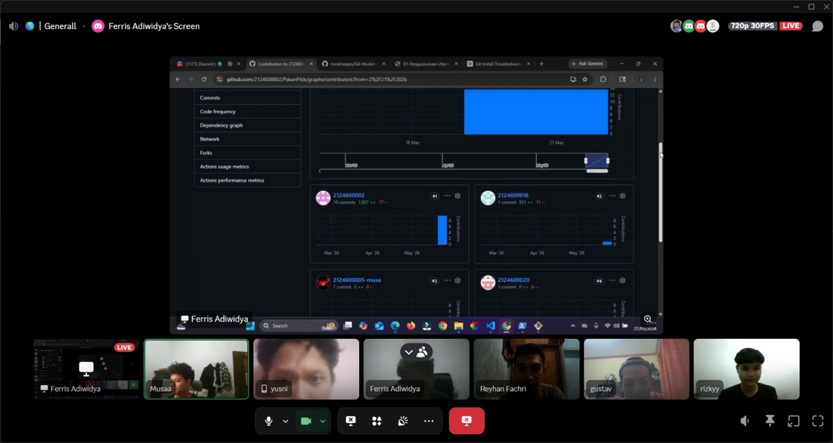
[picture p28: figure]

Diskusi Project

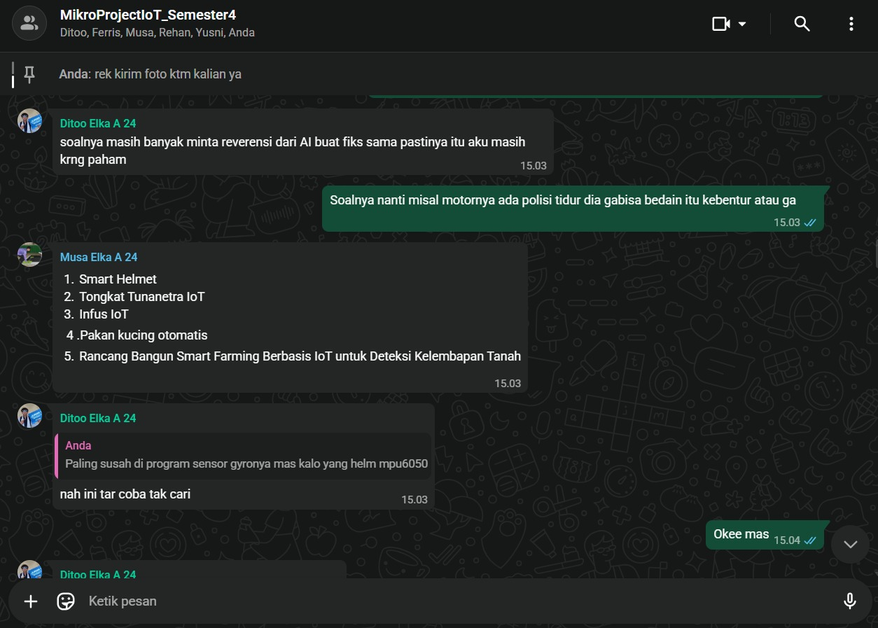
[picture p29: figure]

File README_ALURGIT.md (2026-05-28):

# README_ALURGIT.md

# 📌 Alur Kerja GitHub Project PakanPitik

Dokumen ini digunakan sebagai panduan kerja seluruh anggota tim dalam menggunakan Git & GitHub pada project **PakanPitik** agar workflow tetap rapi, aman, dan terstruktur.

---

# 👨‍💻 Struktur Tim

| Role | Tugas |
| --- | --- |
| Ketua | Review Pull Request, merge ke main, mengatur repository |
| Anggota | Mengerjakan fitur pada branch masing-masing |

---

# 🔒 Aturan Penting

## ❌ DILARANG

* Push langsung ke branch `main`
* Mengubah branch anggota lain
* Menghapus file project tanpa izin
* Force push ke `main`
* Commit file `.pio` atau `.vscode`

---

## ✅ WAJIB

* Kerja di branch masing-masing
* Pull update terbaru sebelum coding
* Commit dengan pesan yang jelas
* Membuat Pull Request setelah selesai bekerja

---

# 🌳 Struktur Branch

| Branch | Fungsi |
| --- | --- |
| `main` | Branch utama project |
| `dito` | Branch kerja Dito |
| `ferris` | Branch kerja Ferris  |
| `musa` | Branch kerja Musa |
| `reyhan` | Branch kerja Reyhan  |
| `yusni`  | Branch kerja Yusni |

---

# 🚀 LANGKAH AWAL SETELAH DIINVITE

---

## 1. Clone Repository

Buka terminal VS Code lalu jalankan:

```bash
git clone git@github.com:2124600002/PakanPitik.git
```

---

## 2. Masuk ke Folder Project

```bash
cd PakanPitik
```

---

## 3. Checkout ke Branch Masing-Masing

Contoh:

```bash
git checkout ferris
```

Ganti `ferris` sesuai nama branch masing-masing anggota.

---

# 🔄 ALUR KERJA HARIAN

Lakukan langkah berikut setiap sebelum dan sesudah bekerja.

---

# 📥 SEBELUM MULAI CODING

## 1. Pastikan berada di branch sendiri

```bash
git branch
```

Jika belum:

```bash
git checkout namabranch
```

---

## 2. Ambil Update Terbaru dari Main

```bash
git pull origin main
```

Tujuan:

* mendapatkan update terbaru dari ketua
* menghindari conflict
* sinkronisasi project

---

# 💻 SETELAH SELESAI CODING

## 1. Tambahkan perubahan

```bash
git add .
```

---

## 2. Commit perubahan

```bash
git commit -m "menambahkan fitur monitoring sensor"
```

Gunakan pesan commit yang jelas dan profesional.

Contoh commit yang baik:

✅

```text
menambahkan pembacaan sensor suhu
memperbaiki bug tombol manual
menambahkan dashboard monitoring
```

❌

```text
fix
baru
update
hehe
```

---

## 3. Push ke Branch Masing-Masing

```bash
git push
```

---

# 🔀 MEMBUAT PULL REQUEST

Setelah push berhasil:

1. Buka repository GitHub
2. Klik tab `Pull Requests`
3. Klik `New Pull Request`
4. Pilih:

   * Base: `main`
   * Compare: `branch masing-masing`
5. Klik `Create Pull Request`

Tambahkan deskripsi perubahan yang dilakukan.

---

# 👑 ALUR REVIEW KETUA

Ketua akan:

1. Review perubahan pada Pull Request
2. Mengecek file yang diubah
3. Memberikan revisi jika diperlukan
4. Approve Pull Request
5. Merge ke branch `main`

---

# 🔄 SETELAH PULL REQUEST DI-MERGE

Semua anggota wajib update branch masing-masing:

```bash
git pull origin main
```

Agar branch tetap sinkron dengan project terbaru.

---

# 🛠 COMMAND PENTING

| Command | Fungsi |
| --- | --- |
| `git status` | Melihat perubahan file |
| `git branch` | Melihat branch aktif |
| `git checkout nama` | Pindah branch |
| `git add .` | Menambahkan semua perubahan |
| `git commit -m "pesan"` | Menyimpan perubahan |
| `git push` | Upload perubahan ke GitHub |
| `git pull origin main`  | Mengambil update terbaru dari main |
| `git log --oneline` | Melihat riwayat commit |

---

# ⚠️ JIKA TERJADI ERROR

## Repository belum update

```bash
git pull origin main
```

---

## Conflict saat merge

Segera hubungi ketua project sebelum melanjutkan.

---

## Salah branch

Pindah branch:

```bash
git checkout namabranch
```

---

# 📌 Catatan Tambahan

* Branch `main` adalah branch paling penting.
* Semua perubahan wajib melalui Pull Request.
* Jangan commit file yang tidak diperlukan.
* Biasakan commit secara rutin.
* Pull update terbaru sebelum coding.

---

# ✅ Workflow Singkat

```text
Pull update terbaru
↓
Coding di branch sendiri
↓
git add .
↓
git commit
↓
git push
↓
Buat Pull Request
↓
Ketua review
↓
Merge ke main
↓
Semua anggota pull update terbaru
```

---

# 🚀 PakanPitik Team Workflow

Developed with structured Git collaboration workflow.

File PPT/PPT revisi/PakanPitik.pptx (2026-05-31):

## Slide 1


UI UX Design

Project Manager

Software & Documentation

Hardware

Software & Documentation

Hardware

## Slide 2


Mind Map Figjam

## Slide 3

Masalah Nyata

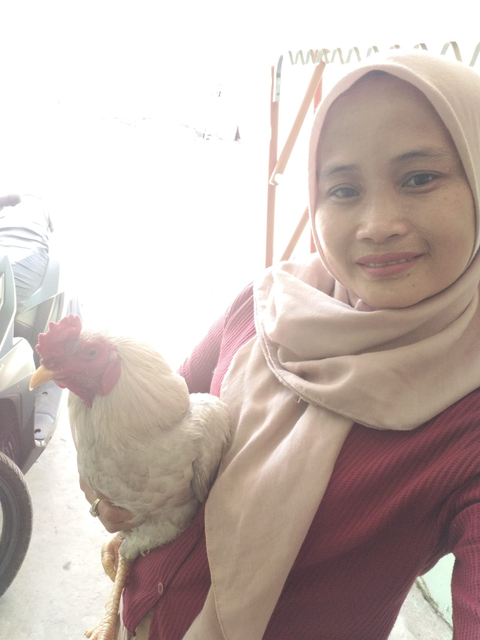
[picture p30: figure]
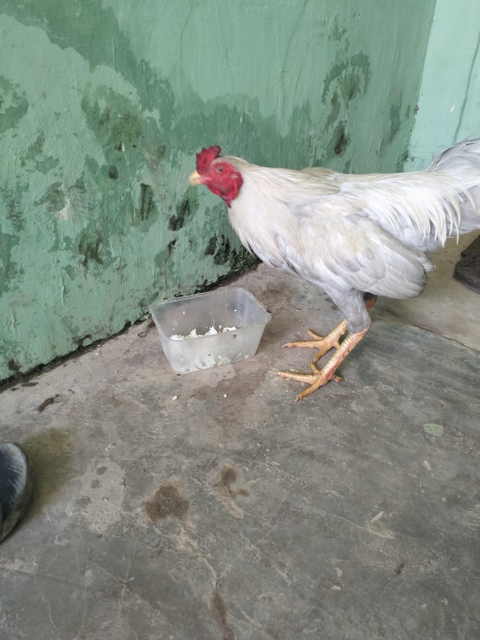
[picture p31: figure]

Rutinitas kerja yang padat membuat pemberian pakan ayam tidak terjadwal dengan konsisten. Keterlambatan atau kelupaan dalam memberi pakan menyebabkan pertumbuhan ayam tidak optimal dan memicu stres pada unggas. Selain itu, pemberian pakan manual yang seringkali "seadanya" berisiko tinggi menyebabkan pakan tercecer atau terbuang sia-sia (food waste), yang menambah beban biaya operasional.

"Terkadang saya harus berangkat kerja pagi sekali dan baru pulang sore hari. Seringkali saya baru ingat memberi pakan siang saat sudah di tempat kerja. Kalaupun ingat, saya terpaksa memberi pakan dalam jumlah banyak sekaligus agar ayam tidak kelaparan, tapi malah banyak yang tumpah dan terinjak-injak karena wadahnya tidak memadai." — Ibu Rizky (Calon Pengguna)

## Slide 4


Fishbone Diagram Figjam

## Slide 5

Sustainable Development Goals Impact


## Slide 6

Block Diagram dan Tabel Mapping

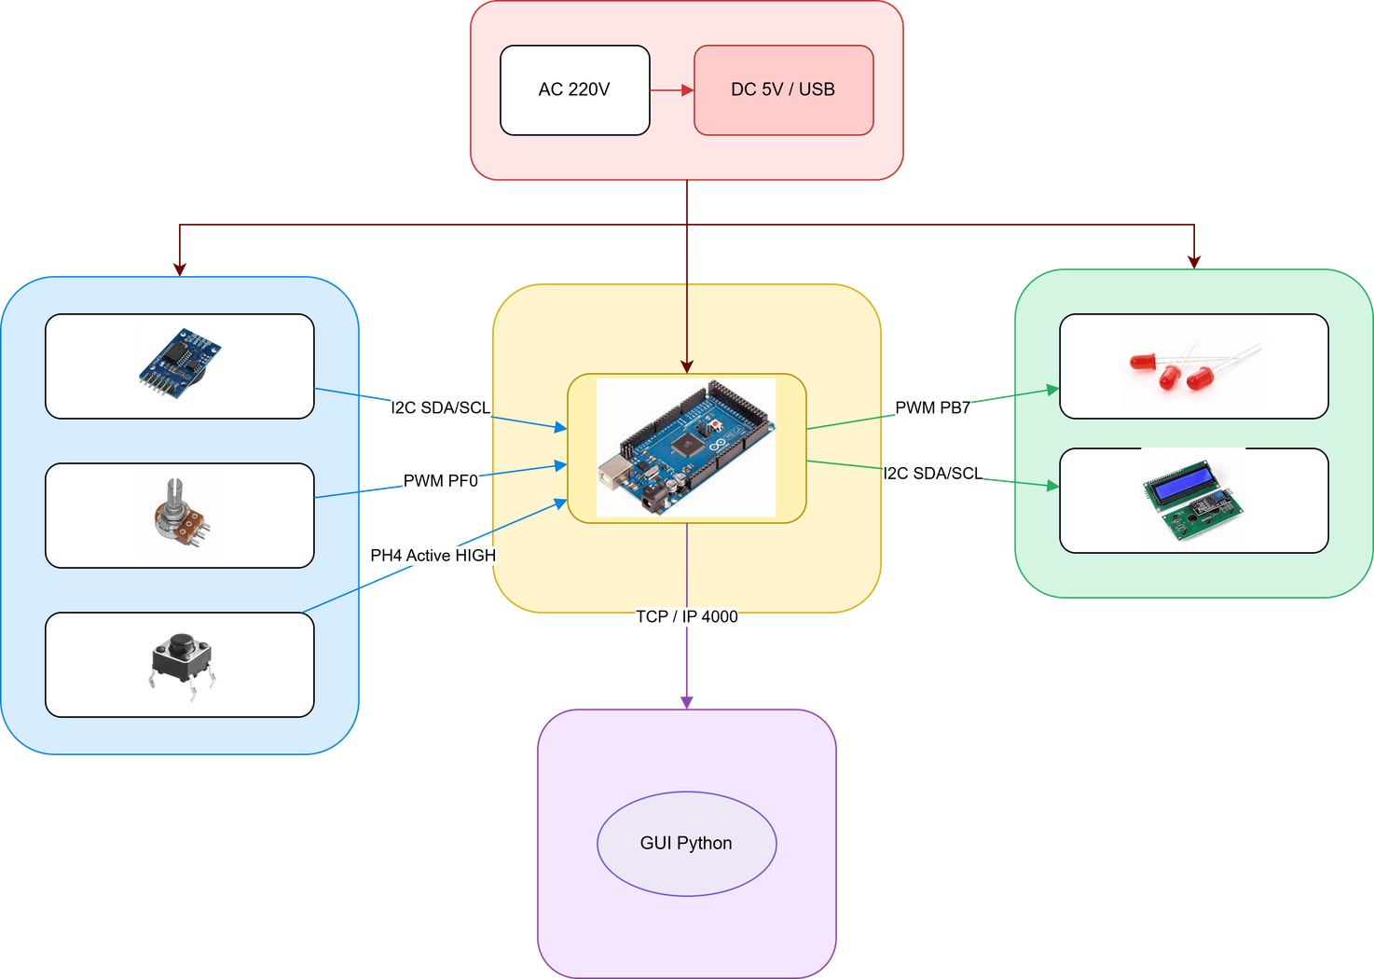
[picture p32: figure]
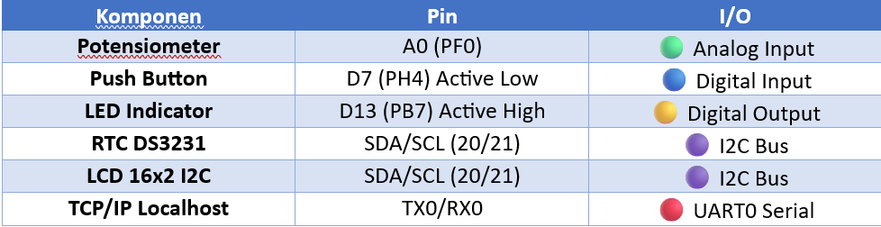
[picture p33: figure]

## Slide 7

UI/UX dan Desain 3D

UI/UX

Desain 3D

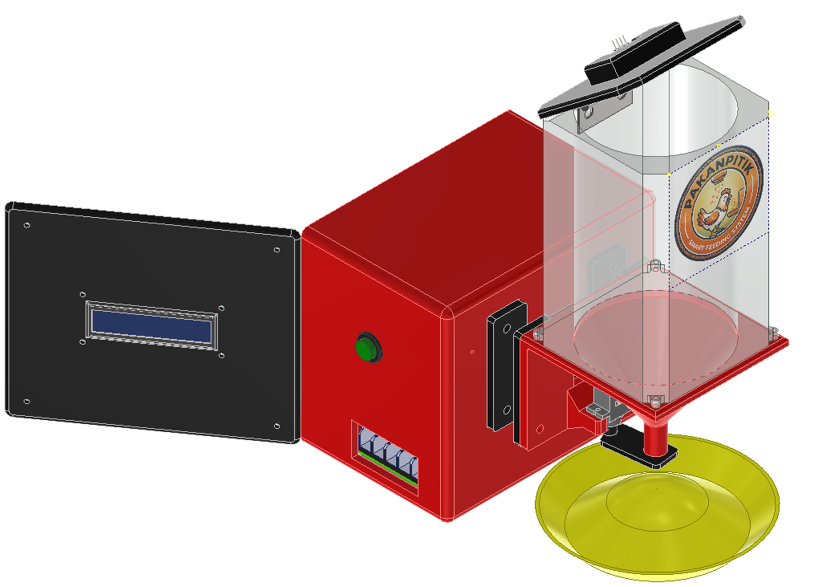
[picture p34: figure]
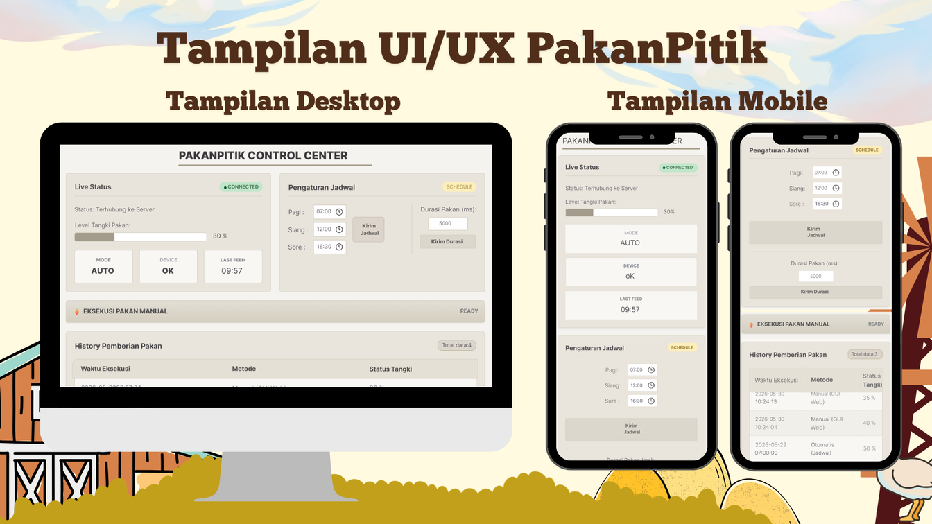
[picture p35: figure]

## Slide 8

Pin Mapping dan RAB

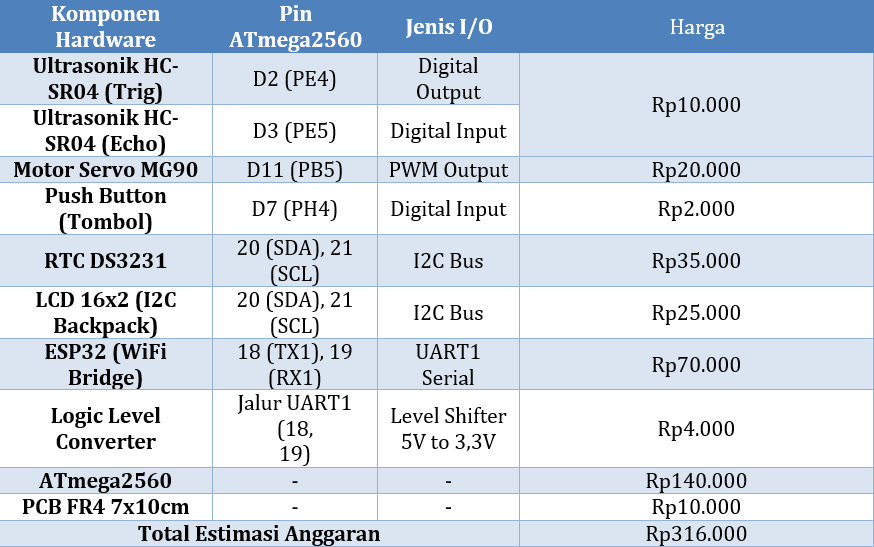
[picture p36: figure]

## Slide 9

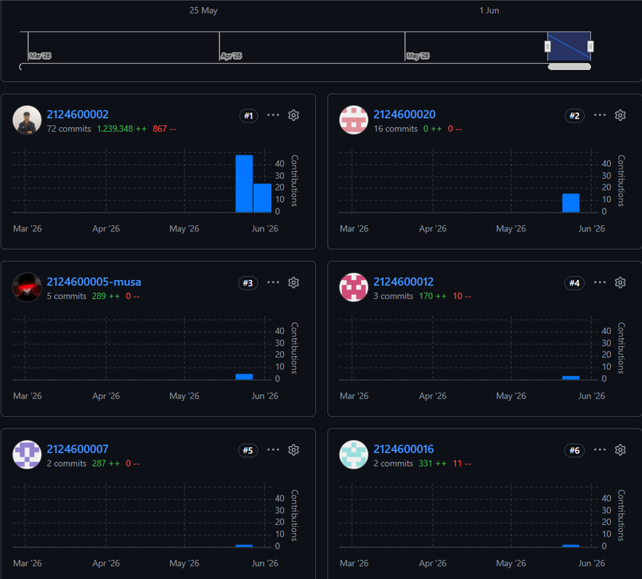
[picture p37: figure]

Dokumentasi Pengerjaan

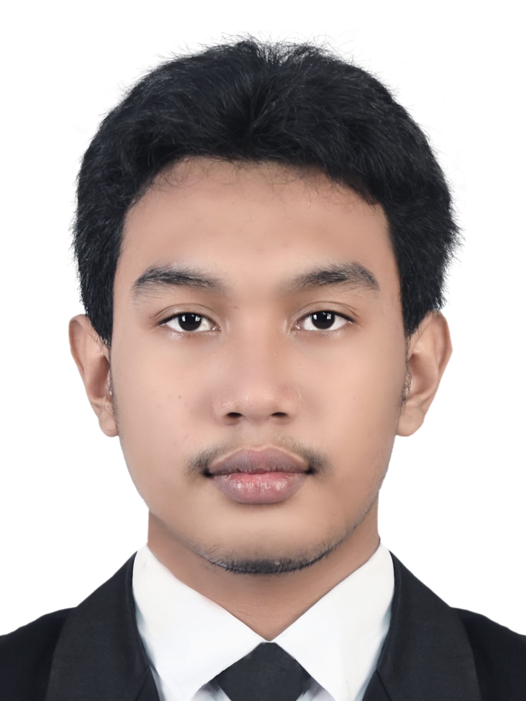
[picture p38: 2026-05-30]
Assets/Foto anggota kelompok/Reyhan Fachri A.H._2124600016.jpeg

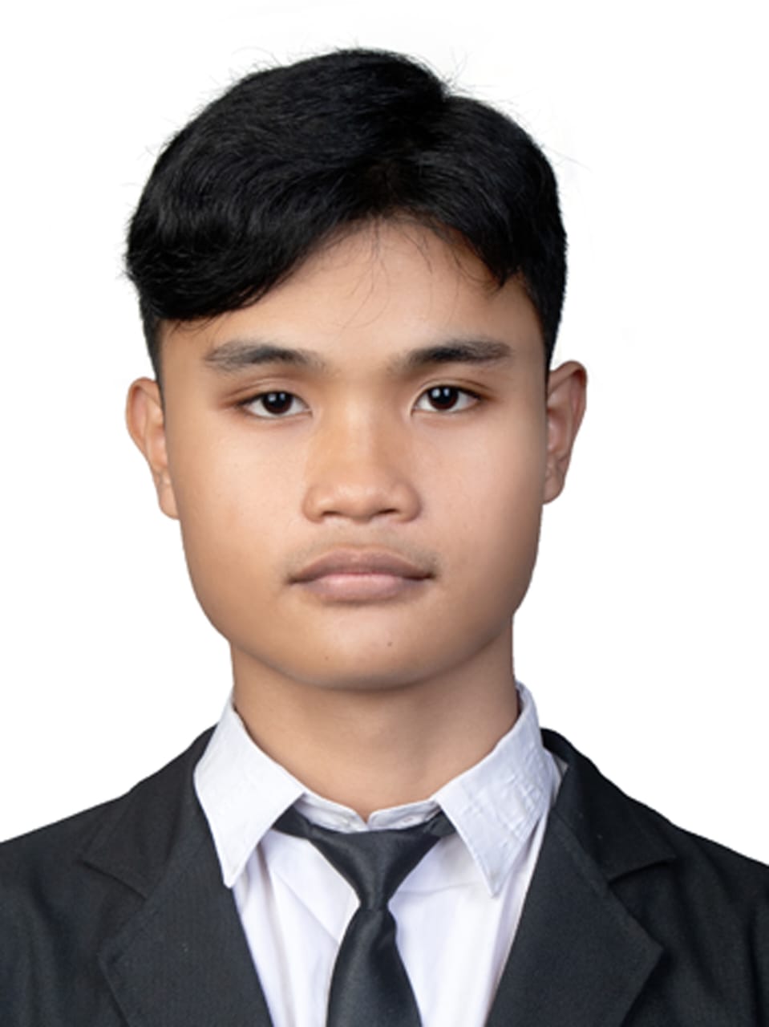
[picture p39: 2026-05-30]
Assets/Foto anggota kelompok/M. Rizky Ramadhan_2124600002.jpeg

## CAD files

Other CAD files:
3D Design/BoxIoT.ipt
3D Design/BracketPenghubung.ipt
3D Design/CorongBawah.ipt
3D Design/ManganPitik.iam
3D Design/OldVersions/BoxIoT.0032.ipt
3D Design/OldVersions/BracketPenghubung.0007.ipt
3D Design/OldVersions/CorongBawah.0057.ipt
3D Design/OldVersions/ManganPitik.0041.iam
3D Design/OldVersions/Tank.0027.ipt
3D Design/OldVersions/TutupAtas.0044.ipt
3D Design/OldVersions/TutupBox.0006.ipt
3D Design/OldVersions/Wadah.0003.ipt
3D Design/Part3.ipt
3D Design/Tank.ipt
3D Design/TutupAtas.ipt
3D Design/TutupBox.ipt
3D Design/TutupTank.ipt
3D Design/Wadah.ipt

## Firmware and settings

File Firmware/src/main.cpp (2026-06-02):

/*
 * PakanPitik v8.1.1 - Master Controller Firmware (SSOT & Dynamic Duration)
 * Architecture: Pure AVR Bare-Metal C++ (ATmega2560)
 * Hardware Connections:
 * - USART0: TCP Bridge Wokwi / USB Laptop (Python HMI Logger)
 * - Timer 1 Fast PWM: Pin 11 (PB5/OC1A) -> Motor Servo MG996R
 * - Timer 3 Polling Timing: Pin D2 (PE4/Trig), Pin D3 (PE5/Echo) -> HC-SR04
 * - TWI (I2C): Pin 20 (SDA), Pin 21 (SCL) -> RTC DS1307/DS3231 & LCD 16x2 Backpack
 * - Digital Input: Pin D7 (PH4) -> Manual Feed Push Button
 */

#include <avr/io.h>
#include <util/delay.h>
#include <avr/interrupt.h>
#include <stdio.h>
#include <string.h>
#include <stdlib.h> 

// --- DEFINISI OPERASI SERVO (TIMER 1) ---
#define SERVO_TUTUP 2000  // Duty cycle ~1ms (Katup Tertutup Rapat)
#define SERVO_BUKA  4000  // Duty cycle ~2ms (Katup Terbuka Penuh)

// --- DEFINISI DRIVER LCD I2C (PCF8574T) ---
// PERBAIKAN PENTING: Alamat 0x27 WAJIB digeser 1 bit ke kiri (<< 1) untuk protokol hardware I2C
#define LCD_ADDR         (0x27 << 1)  // Menjadi 0x4E (Format Tulis / Write Bit = 0)
#define LCD_REG_SELECT   0x01  // Register Select (RS Bit)
#define LCD_ENABLE       0x04  // Enable Bit (EN Bit)
#define LCD_BACKLIGHT    0x08  // Backlight Control Bit

// --- BUFFER KOMUNIKASI USART0 ---
#define BUF_SIZE 32
volatile char rx_buffer[BUF_SIZE];
volatile uint8_t rx_index = 0;
volatile uint8_t cmd_ready = 0;

// --- STRUKTUR DATA WAKTU & SISTEM ---
typedef struct {
    uint8_t jam;
    uint8_t menit;
    uint8_t detik;
} WaktuSistem;

volatile uint8_t flag_beri_makan = 0;

// Jadwal Default: 07:00, 12:00, 16:30
uint8_t jadwal_jam[3] = {7, 12, 16};
uint8_t jadwal_menit[3] = {0, 0, 30};

// --- TAMBAHAN BARU: Variabel Durasi Pakan (dalam milidetik) ---
uint16_t durasi_pakan_ms = 5000; // Default: Buka selama 5000 ms (5 detik)

// =========================================================================
// 1. DRIVER UNIVERSAL ASYNCHRONOUS RECEIVER TRANSMITTER (USART0)
// =========================================================================
void usart0_init(uint32_t baud) {
    uint16_t ubrr_val = (F_CPU / 16 / baud) - 1;
    UBRR0H = (unsigned char)(ubrr_val >> 8);
    UBRR0L = (unsigned char)(ubrr_val);
    
    // Aktifkan Transmitter, Receiver, dan Interupsi RX Complete
    UCSR0B = (1 << RXCIE0) | (1 << RXEN0) | (1 << TXEN0);
    // Atur format frame: 8 data-bit, 1 stop bit, tanpa parity
    UCSR0C = (1 << UCSZ01) | (1 << UCSZ00);
}

void usart0_transmit(char data) {
    while (!(UCSR0A & (1 << UDRE0))); // Tunggu buffer transmit kosong
    UDR0 = data;
}

void usart0_print(const char* str) {
    while (*str) {
        usart0_transmit(*str++);
    }
}

// Interupsi USART0 untuk Menangkap Perintah dari GUI Python Laptop
ISR(USART0_RX_vect) {
    char c = UDR0;
    if (c == '\n' || c == '\r') {
        if (rx_index > 0) {
            rx_buffer[rx_index] = '\0';
            cmd_ready = 1;
        }
    } else if (rx_index < BUF_SIZE - 1) {
        rx_buffer[rx_index++] = c;
    }
}

// =========================================================================
// 2. DRIVER TWO-WIRE INTERFACE (TWI / I2C) MURNI
// =========================================================================
void twi_init(void) {
    TWSR = 0x00; // Prescaler = 1
    TWBR = 72;   // SCL Frequency = 100 kHz (Spesifikasi standar I2C)
    TWCR = (1 << TWEN);
}

void twi_start(void) {
    TWCR = (1 << TWINT) | (1 << TWSTA) | (1 << TWEN);
    while (!(TWCR & (1 << TWINT)));
}

void twi_stop(void) {
    TWCR = (1 << TWINT) | (1 << TWSTO) | (1 << TWEN);
    while (TWCR & (1 << TWSTO));
}

void twi_write(uint8_t data) {
    TWDR = data;
    TWCR = (1 << TWINT) | (1 << TWEN);
    while (!(TWCR & (1 << TWINT)));
}

uint8_t twi_read_ack(void) {
    TWCR = (1 << TWINT) | (1 << TWEN) | (1 << TWEA);
    while (!(TWCR & (1 << TWINT)));
    return TWDR;
}

uint8_t twi_read_nack(void) {
    TWCR = (1 << TWINT) | (1 << TWEN);
    while (!(TWCR & (1 << TWINT)));
    return TWDR;
}

// =========================================================================
// 3. DRIVER LCD CHARACTER 16x2 LEWAT PCF8574 BACKPACK
// =========================================================================
void lcd_pcf_write(uint8_t data) {
    twi_start();
    twi_write(LCD_ADDR); // Sekarang LCD_ADDR sudah bergeser bit dengan benar
    twi_write(data | LCD_BACKLIGHT);
    twi_stop();
}

void lcd_pulse(uint8_t data) {
    lcd_pcf_write(data | LCD_ENABLE);
    _delay_us(2);
    lcd_pcf_write(data & ~LCD_ENABLE);
    _delay_us(50);
}

void lcd_send(uint8_t val, uint8_t mode) {
    uint8_t high_nibble = val & 0xF0;
    uint8_t low_nibble = (val << 4) & 0xF0;
    lcd_pulse(high_nibble | mode);
    lcd_pulse(low_nibble | mode);
}

void lcd_command(uint8_t cmd) { lcd_send(cmd, 0); }
void lcd_data(uint8_t data) { lcd_send(data, LCD_REG_SELECT); }

void lcd_init(void) {
    _delay_ms(50);
    lcd_pulse(0x30);
    _delay_ms(5);
    lcd_pulse(0x30);
    _delay_us(150);
    lcd_pulse(0x30);
    lcd_pulse(0x20); // Pindah ke Mode 4-Bit Data Interface
    
    lcd_command(0x28); // Pengaturan 2 baris, font 5x8
    lcd_command(0x0C); // Display On, Cursor Off
    lcd_command(0x06); // Auto-increment kursor
    lcd_command(0x01); // Bersihkan Layar LCD
    _delay_ms(2);
}

void lcd_set_cursor(uint8_t col, uint8_t row) {
    uint8_t row_offsets[] = {0x00, 0x40};
    lcd_command(0x80 | (col + row_offsets[row]));
}

void lcd_print(const char* str) {
    while (*str) lcd_data(*str++);
}

// =========================================================================
// 4. DRIVER REAL-TIME CLOCK (RTC DS1307 / DS3231)
// =========================================================================
uint8_t bcd_to_dec(uint8_t val) { return ((val / 16) * 10) + (val % 16); }
uint8_t dec_to_bcd(uint8_t val) { return ((val / 10) * 16) + (val % 10); }

void rtc_get_time(WaktuSistem* t) {
    twi_start();
    twi_write(0xD0); // Alamat tulis RTC (0x68 << 1)
    twi_write(0x00); // Set pointer memori ke register 0x00 (Detik)
    
    twi_start();     // Repeated Start
    twi_write(0xD1); // Alamat baca RTC
    
    t->detik = bcd_to_dec(twi_read_ack() & 0x7F);
    t->menit = bcd_to_dec(twi_read_ack());
    t->jam   = bcd_to_dec(twi_read_nack());
    
    twi_stop();
}

// =========================================================================
// 5. DRIVER KENDALIAN ACTUATOR SERVO (TIMER 1 FAST PWM MODE 14)
// =========================================================================
void servo_init(void) {
    DDRB |= (1 << PB5); // Konfigurasi Pin 11 (PB5/OC1A) Menjadi Output
    
    // Fast PWM Mode 14 (TOP diatur oleh ICR1)
    // Clear OC1A pada Compare Match, Set OC1A pada BOTTOM (Non-Inverting)
    TCCR1A = (1 << COM1A1) | (1 << WGM11);
    // Prescaler 8
    TCCR1B = (1 << WGM13) | (1 << WGM12) | (1 << CS11);
    
    ICR1 = 39999;      // Frekuensi Pulsa Pas 50 Hz (Periode = 20ms)
    OCR1A = SERVO_TUTUP; // Kondisi Awal: Katup Pakan Terkunci Rapat
}

void eksekusi_pakan(uint16_t durasi_ms) {
    OCR1A = SERVO_BUKA; // Putar servo ke posisi buka katup pakan
    
    // Delay non-blocking ringan untuk membiarkan pakan jatuh sesuai durasi
    for (uint16_t i = 0; i < durasi_ms / 10; i++) {
        _delay_ms(10);
    }
    
    OCR1A = SERVO_TUTUP; // Kembalikan servo ke posisi mengunci rapat
}

// =========================================================================
// 6. DRIVER SENSOR ULTRASONIK (HC-SR04 PULSE TIMING VIA TIMER 3)
// =========================================================================
void ultrasonic_init(void) {
    DDRE |= (1 << PE4);   // Pin D2 (PE4/Trig) Menjadi Output Trigger
    DDRE &= ~(1 << PE5);  // Pin D3 (PE5/Echo) Menjadi Input Echo
}

uint8_t ambil_level_pakan(void) {
    PORTE &= ~(1 << PE4);
    _delay_us(2);
    PORTE |= (1 << PE4);  // Kirim isyarat Trig HIGH
    _delay_us(10);
    PORTE &= ~(1 << PE4);  // Kembalikan ke LOW
    
    uint32_t counter = 0;
    // Tunggu hingga pin Echo berubah status menjadi HIGH
    while (!(PINE & (1 << PE5))) {
        if (++counter > 50000) return 0; // Proteksi Timeout jika sensor lepas
    }
    
    TCNT3 = 0;
    TCCR3B = (1 << CS31); // Aktifkan Timer 3, Prescaler 8 (Resolusi 0.5 us per tick)
    
    // Hitung durasi selama pulsa Echo berlogika HIGH
    while (PINE & (1 << PE5)) {
        if (TCNT3 > 60000) break; // Pembatasan jarak maksimal pantulan
    }
    TCCR3B = 0; // Matikan Timer 3
    
    uint32_t ticks = TCNT3;
    uint32_t jarak_cm = (ticks * 0.5) * 0.0343 / 2; // Formula konversi jarak fisika suara
    
    // Pemetaan linear persentase wadah pakan (Tinggi Wadah Maksimal = 25 cm, amplitudo set ke 25)
    if (jarak_cm > 25) jarak_cm = 25; 
    uint8_t persentase_stok = ((25 - jarak_cm) * 100) / 25;
    
    return persentase_stok;
}

// =========================================================================
// 7. PROGRAM UTAMA (MAIN ROUTINE ENTRY POINT)
// =========================================================================
int main(void) {
    // Inisialisasi Seluruh Subsistem Hardware Tingkat Rendah
    usart0_init(115200);
    twi_init();
    lcd_init();
    servo_init();
    ultrasonic_init();
    
    // Atur Pin D7 (PH4) untuk Push Button Manual Feed (Input dengan Pull-Up Internal)
    DDRH &= ~(1 << PH4);
    PORTH |= (1 << PH4);
    
    sei(); // Aktifkan Sakelar Utama Interupsi Global MCU
    
    WaktuSistem rtc_time;
    char buffer_kirim[64];
    char lcd_line1[17];
    char lcd_line2[17];
    
    usart0_print("[PAKANPITIK v8.1.1] Bare-Metal ATmega2560 Active. Dynamic Duration Enabled.\n");
    
    uint8_t sumber_pakan = 0; // 1: Jadwal, 2: Tombol Fisik, 3: Perintah GUI

    while (1) {
        // 1. Ambil Data Aktual Sensor & Penjadwal Waktu
        rtc_get_time(&rtc_time);
        uint8_t stok_pakan = ambil_level_pakan();
        
        // 2. Transmisi Data Status Mentah Berformat ke Python Laptop via USB (USART0)
        sprintf(buffer_kirim, "TIME:%02d:%02d:%02d|STOK:%d|JADWAL:%02d:%02d\n", 
                rtc_time.jam, rtc_time.menit, rtc_time.detik, stok_pakan, jadwal_jam[0], jadwal_menit[0]);
        usart0_print(buffer_kirim);
        
        // 3. Tampilkan Informasi Utama pada Layar LCD Lokal
        sprintf(lcd_line1, "JAM : %02d:%02d:%02d  ", rtc_time.jam, rtc_time.menit, rtc_time.detik);
        lcd_set_cursor(0, 0);
        lcd_print(lcd_line1);
        
        sprintf(lcd_line2, "STOK: %d%%    OK ", stok_pakan);
        lcd_set_cursor(0, 1);
        lcd_print(lcd_line2);
        
        // 4. Manajemen Logika Pemicu Jadwal Waktu Makan Otomatis
        for(uint8_t i = 0; i < 3; i++) {
            if (rtc_time.jam == jadwal_jam[i] && rtc_time.menit == jadwal_menit[i] && rtc_time.detik == 0) {
                flag_beri_makan = 1;
                sumber_pakan = 1; // Ditrigger oleh Jadwal Otomatis
            }
        }
        
        // 5. Manajemen Logika Input Kendali Tombol Fisik (Active LOW) - DI PIN D7 / PH4
        if (!(PINH & (1 << PH4))) {
            _delay_ms(20); // Debouncing sakelar mekanik
            if (!(PINH & (1 << PH4))) {
                flag_beri_makan = 1;
                sumber_pakan = 2; // Ditrigger oleh Tombol Fisik Kandang
                while (!(PINH & (1 << PH4))); // Kunci eksekusi hingga tombol dilepas
            }
        }
        
        // 6. Parsing dan Pengenalan Perintah dari GUI Python Laptop via USB
        if (cmd_ready) {
            if (strncmp((const char*)rx_buffer, "#FEED", 5) == 0) {
                flag_beri_makan = 1;
                sumber_pakan = 3; // Ditrigger oleh GUI Python
            } 
            else if (strncmp((const char*)rx_buffer, "#SET:", 5) == 0) {
                uint8_t j1, m1, j2, m2, j3, m3;
                if (sscanf((const char*)rx_buffer, "#SET:%02hhd:%02hhd,%02hhd:%02hhd,%02hhd:%02hhd", 
                           &j1, &m1, &j2, &m2, &j3, &m3) == 6) {
                    jadwal_jam[0] = j1; jadwal_menit[0] = m1;
                    jadwal_jam[1] = j2; jadwal_menit[1] = m2;
                    jadwal_jam[2] = j3; jadwal_menit[2] = m3;
                    usart0_print("[SYSTEM] 3 Jadwal makan baru diperbarui via GUI Laptop.\n");
                }
            }
            // --- LOGIKA DURASI YANG BARU DIPERBAIKI ---
            else if (strncmp((const char*)rx_buffer, "#DUR:", 5) == 0) {
                // Ambil teks angka setelah 5 karakter pertama ("#DUR:") lalu ubah ke Integer
                int durasi_baru = atoi((const char*)rx_buffer + 5);
                
                // PROTEKSI FISIKA MEKANIK: Servo butuh minimal 500ms (0.5 detik) untuk bisa berputar
                if (durasi_baru < 500) {
                    durasi_baru = 500;
                }
                
                durasi_pakan_ms = (uint16_t)durasi_baru; // Update variabel durasi
                
                // Kirim balik konfirmasi ke Python
                char info_durasi[64];
                sprintf(info_durasi, "[SYSTEM] Durasi pakan berhasil diset ke: %u ms.\n", durasi_pakan_ms);
                usart0_print(info_durasi);
            }
            
            rx_index = 0;
            cmd_ready = 0;
        }
        
        // 7. Pusat Eksekusi Penggerak Motor Servo Dispenser Pakan
        if (flag_beri_makan) {
            // KIRIM KONFIRMASI EVENT KE PYTHON SEBELUM DELAY BLOCKING
            if (sumber_pakan == 1)      usart0_print("EVENT:AUTO\n");
            else if (sumber_pakan == 2) usart0_print("EVENT:PHYSICAL\n");
            else if (sumber_pakan == 3) usart0_print("EVENT:GUI\n");

            lcd_set_cursor(0, 1);
            lcd_print("STATUS: FEEDING ");
            
            // --- PERUBAHAN: Gunakan variabel durasi, bukan angka statis ---
            eksekusi_pakan(durasi_pakan_ms); 
            
            // Reset state
            flag_beri_makan = 0;   
            sumber_pakan = 0;
        }
        
        _delay_ms(200); // Jeda siklus pembacaan sistem teratur
    }
    return 0;
}

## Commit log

2026-05-26 menambahkan file 3D awal
    [CorongBawah.ipt, ManganPitik.iam, Tank.ipt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]
2026-05-27 update untuk design 3D
    [CorongBawah.0050.ipt, CorongBawah.ipt, ManganPitik.0018.iam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]
2026-05-27 update tank pada 3D
    [ManganPitik.0018.iam, ManganPitik.0019.iam, ManganPitik.iam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]
2026-05-27 membuat firmware sesuai shield
    [ManganPitik.0019.iam, ManganPitik.0021.iam, ManganPitik.iam]
2026-05-27 Flowchart sistem nyata
2026-05-28 menambahkan folder UI-UX
    [CorongBawah.0050.ipt, CorongBawah.0051.ipt, CorongBawah.ipt]
2026-05-29 menambahkan fitur pengatur durasi buka dari servo katup penampung
2026-05-29 menambahkan fitur pengatur lamanya servo dibuka pada program yang sesuai dengan shield
2026-05-29 menambahkan flowchart dan blockdiagram baru
2026-05-29 memperjelas flowchart
2026-05-29 menambahkan desain PCB dan skematik dari hardware tambahan selain shield ATmega2560
    [BracketPenghubung.0007.ipt, BracketPenghubung.ipt, CorongBawah.0051.ipt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]
2026-05-29 Desain 3D update untuk semua bagian
    [BoxIoT.0030.ipt, BoxIoT.ipt, CorongBawah.0056.ipt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]
2026-05-30 membuat web agar bisa responsif pada berbagai device selain laptop dengan menambahkan bagian di koding css paling akhir
    [ManganPitik.0035.iam, ManganPitik.0036.iam, ManganPitik.iam]
2026-05-30 merubah dan merapihkan README.md
    [BoxIoT.0030.ipt, BoxIoT.0032.ipt, BoxIoT.ipt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]
2026-05-30 mengganti gambar UI-UX yang ditampilkan pada README.md agar lebih menarik
    [ManganPitik.0036.iam, ManganPitik.0037.iam, ManganPitik.iam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]
2026-05-30 pemberian deskripsi pada setiap gambar
    [ManganPitik.0037.iam, ManganPitik.0039.iam, ManganPitik.iam]
2026-05-30 memperkecil flowchart agar tidak terlalu zoom
2026-05-30 memperbaiki beberapa typo pada kalimat di README.md
2026-06-03 menambahkan link video animasi 3D
    [ManganPitik.0039.iam, ManganPitik.0040.iam, ManganPitik.iam]
2026-06-12 menambahkan Vidio Demo Project Full Anggota Kelompok
    [ManganPitik.0040.iam, ManganPitik.0041.iam, ManganPitik.iam]
2026-06-12 menambahkan vidio Demo Full Anggota Kelompok pada LINK di README.md github
